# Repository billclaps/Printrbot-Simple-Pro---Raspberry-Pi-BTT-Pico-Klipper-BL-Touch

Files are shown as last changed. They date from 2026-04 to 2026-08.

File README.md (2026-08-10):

# Printrbot Simple Pro — Raspberry Pi + BTT SKR Pico + Klipper + BLTouch Conversion

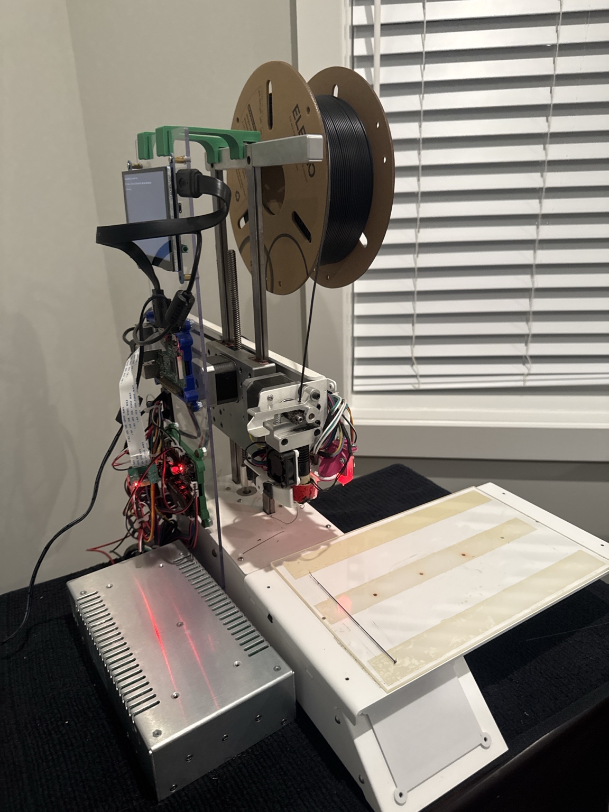
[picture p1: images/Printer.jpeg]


## Overview

This project documents the modernization of a **Printrbot Simple Pro** by replacing the original control electronics with a **BigTreeTech SKR Pico** running **Klipper** and a **Raspberry Pi 3B+**.

The objective was to transform this legacy printer into a modern, reliable, and highly tunable machine while retaining the original mechanical platform.

This repository includes the hardware configuration, firmware, slicer profiles, printer configuration, tuning notes, and lessons learned throughout the conversion.

---

# Hardware

| Component | Description |
|---|---|
| Printer | Printrbot Simple Pro |
| Host | Raspberry Pi 3 Model B+ |
| Controller | BigTreeTech SKR Pico |
| Firmware | Klipper |
| Web Interface | Mainsail |
| API | Moonraker |
| Touchscreen | KlipperScreen |
| Bed Probe | BLTouch |
| Extruder | Stock Printrbot Extruder |
| Hotend | Stock Printrbot Hotend |
| Build Surface | Glass plate mounted with high-strength double-sided tape |
| Cooling | Stock fans (retuned) |

---

# SKR Pico Configuration

The following jumper configuration was found to provide reliable operation.

| Setting | Configuration |
|---|---|
| BOOT Jumper | **Removed** |
| USB Power Jumper | **Removed** |
| USB Power Blocker | **Installed** |
| 12V Supply | **Connected** |

USB connection:

```
Raspberry Pi
      │
      ▼
USB Power Blocker
      │
      ▼
BTT SKR Pico
```

This configuration eliminates USB backfeeding while allowing the Pico to boot reliably from the printer's 12V supply.

---

# Software

- Klipper
- Moonraker
- Mainsail
- KlipperScreen
- OrcaSlicer 2.3.2

---

# Quick Start

## 1. Flash the SKR Pico

Compile Klipper for the following target:

```
Micro-controller Architecture: Raspberry Pi RP2040
Processor Model: RP2040
Bootloader Offset: No bootloader
Flash Chip: W25Q080 with CLKDIV 2
Communication Interface: USB (USBSERIAL)
```

Flash the generated `klipper.uf2` firmware.

---

## 2. Install MainsailOS

Install MainsailOS on a Raspberry Pi and complete the initial network setup.

---

## 3. Copy the Configuration

Copy:

```
printer.cfg
```

into:

```
~/printer_data/config/
```

---

## 4. Update the MCU Serial

Determine the USB device ID:

```bash
ls /dev/serial/by-id/
```

Update the `serial:` entry inside `printer.cfg`.

---

## 5. Restart Klipper

```bash
sudo systemctl restart klipper
```

---

## 6. Verify Motion

- Home all axes
- Verify endstops
- Verify BLTouch
- Verify heaters

---

## 7. Print a Calibration Model

Start with a calibration cube before printing Benchy or larger models.

---

# Current Status

✅ Fully operational

✅ Running Klipper

✅ Stable USB communication

✅ Reliable cold boots

✅ Dimensionally accurate prints

✅ Thermally stable

✅ Pressure Advance tuned

---

# Final Tuned Settings

## PLA

| Setting | Value |
|---|---|
| Nozzle | 0.30 mm |
| Layer Height | 0.20 mm |
| Temperature | 215–220°C |

---

## Klipper

| Setting | Value |
|---|---|
| Pressure Advance | ~0.11 |
| PID Tuning | Completed |

---

## Retraction

| Setting | Value |
|---|---|
| Distance | 0.8 mm |
| Speed | 35 mm/s |
| Wipe | Enabled |
| Z-hop | Disabled |

---

## Cooling

Fan speeds reduced to approximately **30–80%** to maintain hotend thermal stability while providing adequate part cooling.

---

## Print Speed

Approximately **80 mm/s** general print speed.

---

# Tuning Highlights

The following improvements were made during the conversion:

- Corrected extrusion scaling (`rotation_distance`)
- Calibrated PID for stable nozzle temperatures
- Eliminated heater shutdowns
- Resolved G2/G3 arc command compatibility
- Tuned Pressure Advance
- Optimized retraction
- Disabled unnecessary Z-hop
- Balanced cooling for improved surface finish
- Reduced stringing
- Improved dimensional accuracy

---

# Troubleshooting Notes

One particularly difficult issue involved intermittent USB enumeration of the SKR Pico.

The final solution consisted of:

- Removing the BOOT jumper after flashing
- Removing the USB power jumper
- Compiling Klipper firmware directly from the host Raspberry Pi
- Flashing the freshly compiled firmware
- Installing a USB power blocker
- Powering the Pico from the printer's 12V supply

This combination produced reliable cold boots and stable USB communication.

---

# Future Improvements

- Input Shaping
- Accelerometer tuning
- Complete wiring diagrams
- Printable electronics enclosure
- Cable management improvements
- Additional macros

---

# Repository Contents

- `printer.cfg`
- Wiring diagrams
- BLTouch configuration
- OrcaSlicer printer profile
- Macros
- Startup scripts
- Troubleshooting guide
- Photos of the conversion

---

# Notes

Although the electronics have been modernized, the project intentionally preserves the original Printrbot motion system. The goal is to demonstrate what can be achieved with modern firmware while retaining legacy hardware.

---

# Acknowledgements

Many thanks to the Klipper community, BigTreeTech, and the Printrbot community for providing documentation, examples, and inspiration that made this conversion possible.  The "Pro_Fan_Shroud.stl" file was the original from Printrbot. The "new_simple_production_v2_v81_fan_shroud_1_v1.stl" file was created by pmally - https://www.thingiverse.com/thing:3929880 - https://github.com/drphil3d

---

# Contributions

Contributions, suggestions, and improvements are always welcome.

If you're converting a Printrbot to Klipper, feel free to open an issue or submit a pull request.

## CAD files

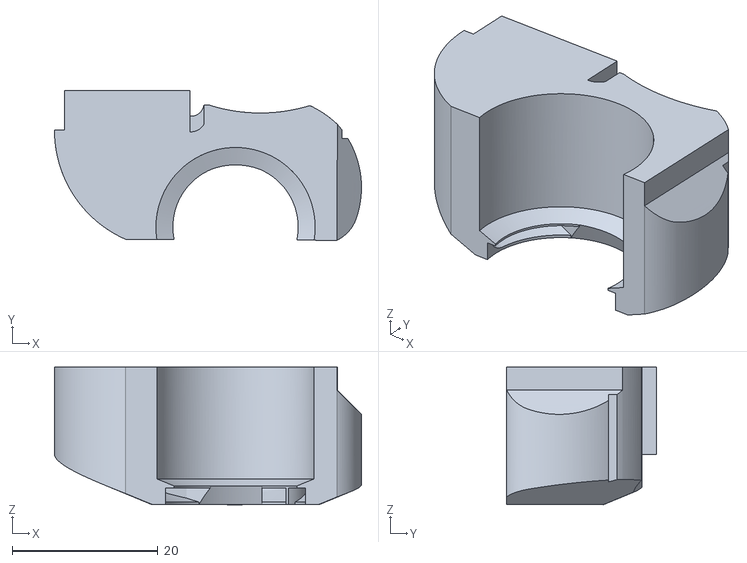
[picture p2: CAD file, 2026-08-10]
new_simple_production_v2_v81_fan_shroud_1_v1.stl
42.1 x 20.5 x 18.9

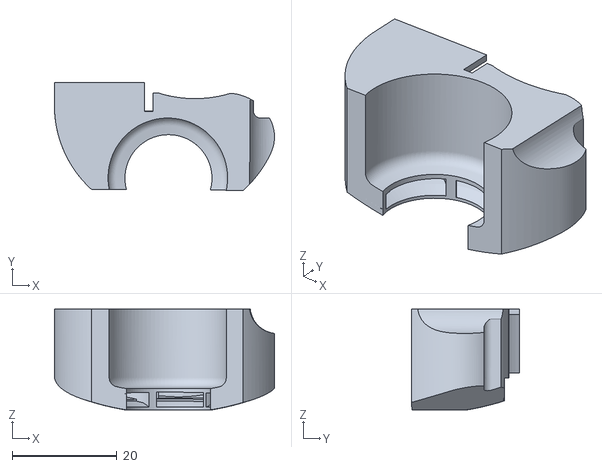
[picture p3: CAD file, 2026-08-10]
Pro_Fan_Shroud.stl
42.1 x 20.6 x 19.3

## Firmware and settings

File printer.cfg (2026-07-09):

# =========================
# PRINTER CONFIG
# Printrbot Simple Pro
# BTT SKR Pico + Raspberry Pi + Klipper
# =========================

[mcu]
serial: /dev/serial/by-id/usb-Klipper_rp2040_4550357127897E58-if00
restart_method: command

[printer]
kinematics: cartesian
max_velocity: 250
max_accel: 1800
max_z_velocity: 10
max_z_accel: 80
square_corner_velocity: 5.0

# --------------------
# X Axis
# --------------------
[stepper_x]
step_pin: gpio11
dir_pin: gpio10
enable_pin: !gpio12
microsteps: 16
rotation_distance: 40
endstop_pin: ^gpio4
position_endstop: 0
position_max: 200
homing_speed: 50

[tmc2209 stepper_x]
uart_pin: gpio9
tx_pin: gpio8
uart_address: 0
run_current: 0.70
stealthchop_threshold: 0

# --------------------
# Y Axis
# --------------------
[stepper_y]
step_pin: gpio6
dir_pin: gpio5
enable_pin: !gpio7
microsteps: 16
rotation_distance: 40
endstop_pin: ^gpio3
position_endstop: 150
position_max: 150
homing_positive_dir: true
homing_speed: 50

[tmc2209 stepper_y]
uart_pin: gpio9
tx_pin: gpio8
uart_address: 2
run_current: 0.70
stealthchop_threshold: 0

# --------------------
# Z Axis
# --------------------
[stepper_z]
step_pin: gpio19
dir_pin: !gpio28
enable_pin: !gpio2
microsteps: 16
rotation_distance: 8
endstop_pin: probe:z_virtual_endstop
position_min: -5
position_max: 200
homing_speed: 8
second_homing_speed: 3

[tmc2209 stepper_z]
uart_pin: gpio9
tx_pin: gpio8
uart_address: 1
run_current: 0.65
stealthchop_threshold: 0

# --------------------
# Extruder
# --------------------
[extruder]
step_pin: gpio14
dir_pin: !gpio13
enable_pin: !gpio15
microsteps: 16
rotation_distance: 25.0
nozzle_diameter: 0.300
filament_diameter: 1.750

heater_pin: gpio23
sensor_pin: gpio27
sensor_type: EPCOS 100K B57560G104F

#control: pid
#pid_kp: 21.5
#pid_ki: 1.06
#pid_kd: 109.0

pressure_advance: 0.11

min_temp: 0
max_temp: 285
min_extrude_temp: 170

[tmc2209 extruder]
uart_pin: gpio9
tx_pin: gpio8
uart_address: 3
run_current: 0.80
stealthchop_threshold: 0

# --------------------
# Bed
# --------------------
#[heater_bed]
#heater_pin: gpio21
#sensor_pin: gpio26
#sensor_type: EPCOS 100K B57560G104F
#control: pid
#pid_kp: 54.0
#pid_ki: 0.77
#pid_kd: 948.0
#min_temp: 0
#max_temp: 110

# --------------------
# Fans
# --------------------
[fan]
pin: gpio17

[heater_fan hotend_fan]
pin: gpio18
heater: extruder
heater_temp: 45.0

# --------------------
# BLTouch
# --------------------
[bltouch]
sensor_pin: ^gpio22
control_pin: gpio29
x_offset: 44
y_offset: 0
z_offset: 3.199
speed: 8
samples: 2
sample_retract_dist: 3.0

# --------------------
# Safe homing
# --------------------
[safe_z_home]
home_xy_position: 80,75
speed: 50
z_hop: 10
z_hop_speed: 10

# --------------------
# Bed mesh
# --------------------
[bed_mesh]
speed: 100
horizontal_move_z: 8
mesh_min: 50,10
mesh_max: 190,140
probe_count: 5,5
algorithm: bicubic

# --------------------
# Optional screws helper
# --------------------
[screws_tilt_adjust]
screw1: 15,15
screw1_name: front_left
screw2: 185,15
screw2_name: front_right
screw3: 185,135
screw3_name: rear_right
screw4: 15,135
screw4_name: rear_left
horizontal_move_z: 8
speed: 100

# --------------------
# Marlin compatibility
# --------------------
[gcode_macro M290]
description: Babystepping (Marlin compatibility)
gcode:
  {% set z = params.Z|default(0)|float %}
  SET_GCODE_OFFSET Z_ADJUST={z} MOVE=1

# --------------------
# Misc
# --------------------

[gcode_arcs]
resolution: 0.1

[pause_resume]

[idle_timeout]
timeout: 900

[display_status]

[virtual_sdcard]
path: ~/printer_data/gcodes

# --------------------
# Convenience aliases
# --------------------
[gcode_macro G29]
gcode:
  BED_MESH_CALIBRATE

# --------------------
# Start Print
# --------------------

[gcode_macro START_PRINT]
gcode:
  {% set EXTRUDER_TEMP = params.EXTRUDER_TEMP|default(210)|float %}

  G90
  M83

  M104 S{EXTRUDER_TEMP}
  M109 S{EXTRUDER_TEMP}

  G28
  BED_MESH_PROFILE LOAD=default

  G1 Z5 F3000
  G1 X5 Y5 F6000
  G1 Z0.3 F1000
  G1 X5 Y140 E10 F1000
  G1 X6 Y140 F6000
  G1 X6 Y5 E10 F1000

  G92 E0
  G1 Z2 F1200

# --------------------
# End Print
# --------------------
[gcode_macro END_PRINT]
gcode:
  M400
  TURN_OFF_HEATERS
  M107
  G91
  G1 Z10 E-2 F1200
  G90
  G1 X10 Y140 F6000
  M84

# --------------------
# Cancel Print
# --------------------
[gcode_macro CANCEL_PRINT]
rename_existing: CANCEL_PRINT_BASE
gcode:
  M400
  TURN_OFF_HEATERS
  M107
  G91
  G1 Z10 F1200
  G90
  G1 X10 Y140 F6000
  CANCEL_PRINT_BASE

# --------------------
# Pause / Resume
# --------------------
[gcode_macro PAUSE]
rename_existing: PAUSE_BASE
gcode:
  PAUSE_BASE
  G91
  G1 Z10 F1200
  G90
  G1 X10 Y140 F6000

[gcode_macro RESUME]
rename_existing: RESUME_BASE
gcode:
  RESUME_BASE

# =========================
# IGNORE UNUSED BED COMMANDS
# =========================

[gcode_macro M140]
gcode:
  # Ignore set bed temp (no heated bed installed)

[gcode_macro M190]
gcode:
  # Ignore wait for bed temp

#*# <---------------------- SAVE_CONFIG ---------------------->
#*# DO NOT EDIT THIS BLOCK OR BELOW. The contents are auto-generated.
#*#
#*# [bed_mesh default]
#*# version = 1
#*# points =
#*# 	0.048750, 0.065000, 0.075000, 0.086250, 0.082500
#*# 	-0.006250, -0.001250, 0.015000, 0.030000, 0.040000
#*# 	-0.011250, -0.015000, -0.001250, 0.025000, 0.043750
#*# 	0.053750, 0.042500, 0.056250, 0.086250, 0.113750
#*# 	0.213750, 0.203750, 0.220000, 0.250000, 0.281250
#*# x_count = 5
#*# y_count = 5
#*# mesh_x_pps = 2
#*# mesh_y_pps = 2
#*# algo = bicubic
#*# tension = 0.2
#*# min_x = 50.0
#*# max_x = 190.0
#*# min_y = 10.0
#*# max_y = 140.0
#*#
#*# [extruder]
#*# control = pid
#*# pid_kp = 37.596
#*# pid_ki = 4.476
#*# pid_kd = 78.951
